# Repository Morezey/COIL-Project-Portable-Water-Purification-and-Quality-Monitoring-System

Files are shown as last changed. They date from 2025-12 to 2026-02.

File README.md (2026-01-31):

# Solar-Powered Water Purification & Quality Monitoring System

**Project Status:** Active | **Current Release:** Version 4 (Final Design)

## 📖 Project Overview
This project implements an automated water purification system with real-time quality monitoring. It features two distinct hardware configurations:
1.  **Scaled System (Part A):** High-capacity community unit (Seaflo Pump, 4-Stage Filtration + UV, solar powered).
2.  **Miniaturized System (Part B):** Portable tactical unit (R385 Pump, UF Membrane, Battery Powered).

---

## 📂 Repository Structure

```text
├── docs/                      # System design documentation
│   ├── version 1/             
│   ├── version 2/             
│   ├── version 3/             
│   └── version 4/            
│       ├── logical flow charts/
│       ├── system architecture/
│       └── system design review-v4.pdf
│
├── firmware/                  # ESP32 Source Code
│
├── hardware/                  # Hardware Design Files
│   ├── BOM/                   # Bill of Materials
│   ├── datasheets/            # Component Specifications
│   ├── PCB design/            # KiCad Project Files
│   └── simulations/           # Proteus Circuit Simulations
│
├── LICENSE
```

## 🚀 Getting Started
*   **Docs:** Start with `docs/version 4/system architecture` to understand the final system layout.
*   **Hardware:** Check the `hardware/simulations` folder to view the verified power and actuator circuits.
```

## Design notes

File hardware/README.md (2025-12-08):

The different files associated with the hardware components are placed here i.e.
- Schematics
- PCB layouts
- 3D models

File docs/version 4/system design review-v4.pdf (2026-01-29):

# Design and Implementation of a portable

# Water Purification and Quality Monitoring

# system

## Contents

PART A: SCALED SYSTEM | 3
1 Project Overview | 3
2 System Architecture and Hardware Layout | 3
3 System Operational Modes | 4
4 User Interface and Water Quality Standards | 9
5 Electrical Design and Simulation | 9
6 Bill of Materials Summary | 12
PART B: MINIATURIZED TACTICAL SYSTEM | 14
7 Project Overview | 14

8 System Architecture | 14
9 System Operational Modes | 15
10 Bill of Materials Summary (Miniaturized) | 20

## PART A: SCALED SYSTEM

## 1 Project Overview

Objective: To design an automated water purification and quality monitoring system prioritizing robust filtration performance, sensor accuracy, and operational safety.
The key features of the system include:
- Multi-stage filtration (Sediment, Carbon, and post filtration).
- UV treatment for disinfection.
- Real-time IoT quality monitoring.
- Automated self-protection mechanisms.

## 2 System Architecture and Hardware Layout

The system is made up of four different filters that operate in the pre-filtration phase, a UV lamp to kill microbial contaminants, and various sensors at different stages used to monitor the system and support the automation of the different actuators.

### 2.1 Hardware Block Diagram

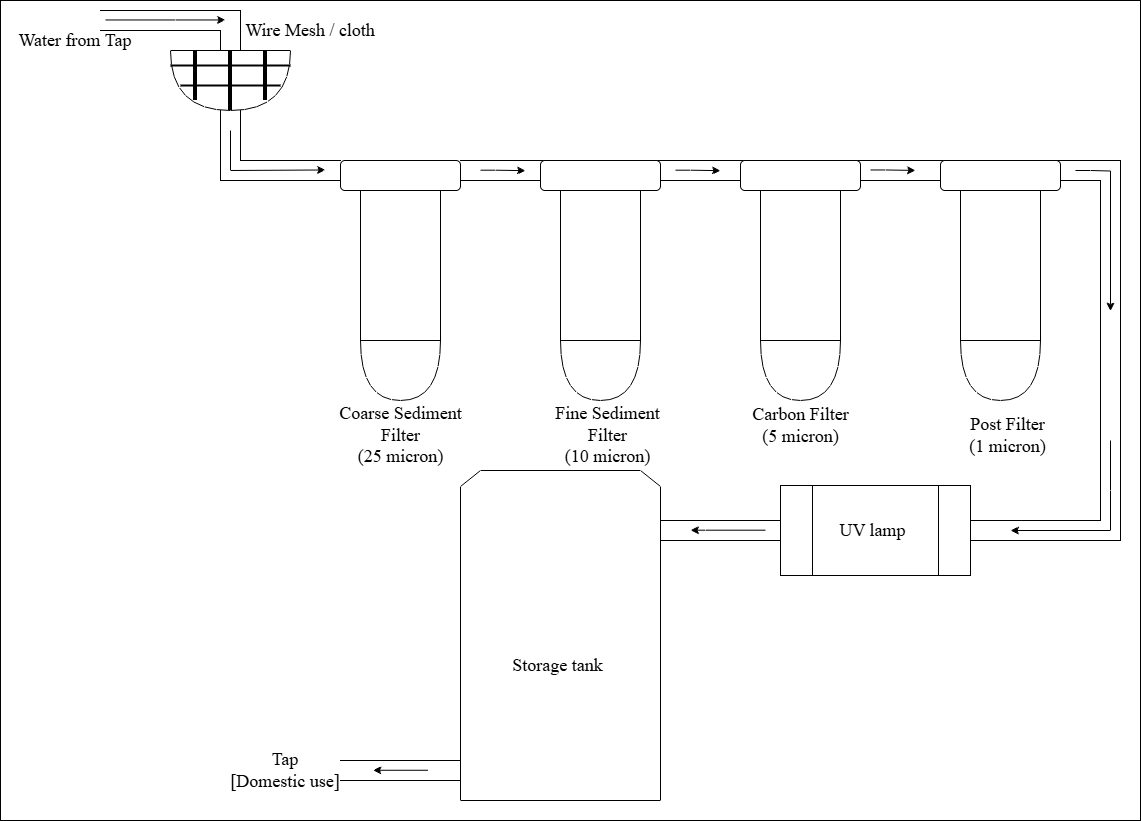
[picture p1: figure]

Figure 1: Hardware block diagram of the system.

### 2.2 Overall system representation

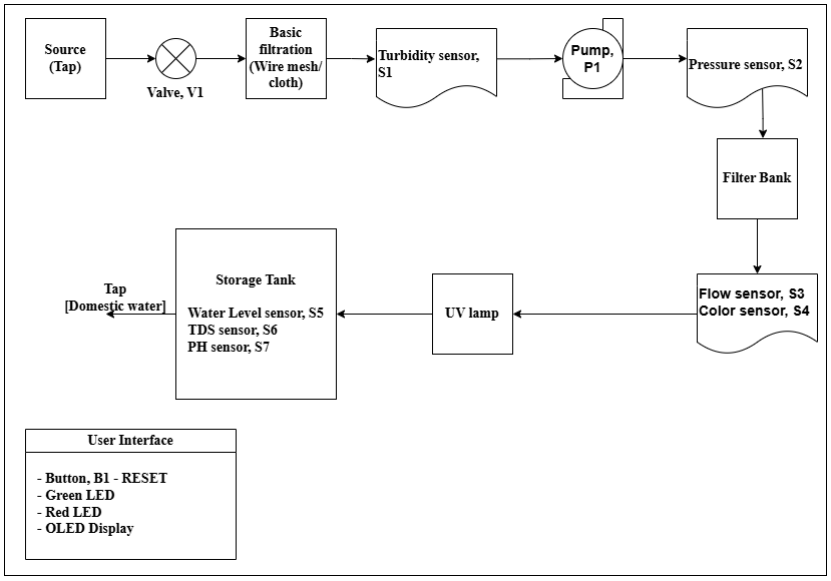
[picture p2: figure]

Figure 2: Overall system schematic representation.

During this stage, raw water is treated before storage. The process includes:
- Filtration: Water is drawn by pump P1 and passed through a filter bank consisting of two sediment filters (25 µm and 10 µm), an activated carbon 5 µm filter, and a 1 µm post-filter.
- System Protection: A pressure sensor (S2) and flow sensor (S3) monitor the

system conditions to detect clogs.
- Disinfection: A UV lamp is installed after the filter bank to reduce microbial load

before water enters the storage tank.

## 3 System Operational Modes

The system is designed with a microcontroller to monitor parameters and automate operations.

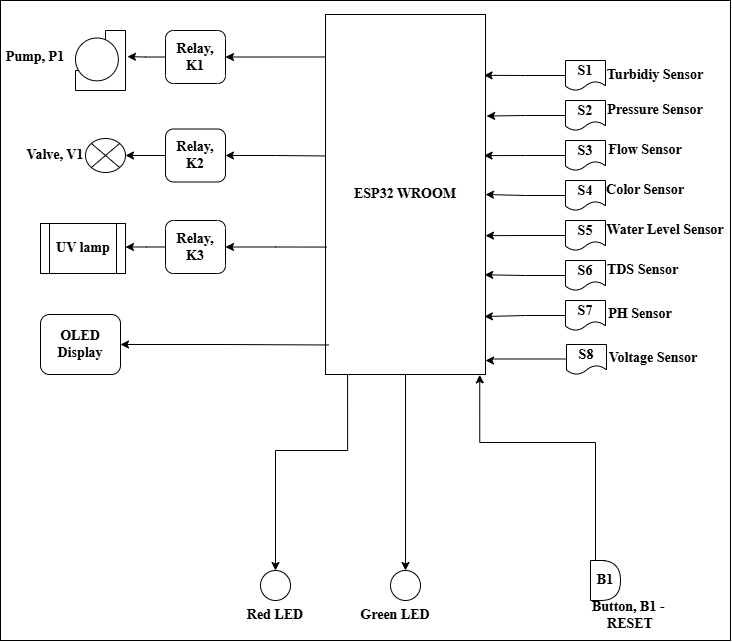
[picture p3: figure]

Figure 3: Microcontroller and component integration.

The microcontroller operates in three distinct modes to ensure safety, fault isolation, and energy efficiency:

### 3.1 Filtration Mode

Objective: To automatically fill the storage tank while protecting hardware components.

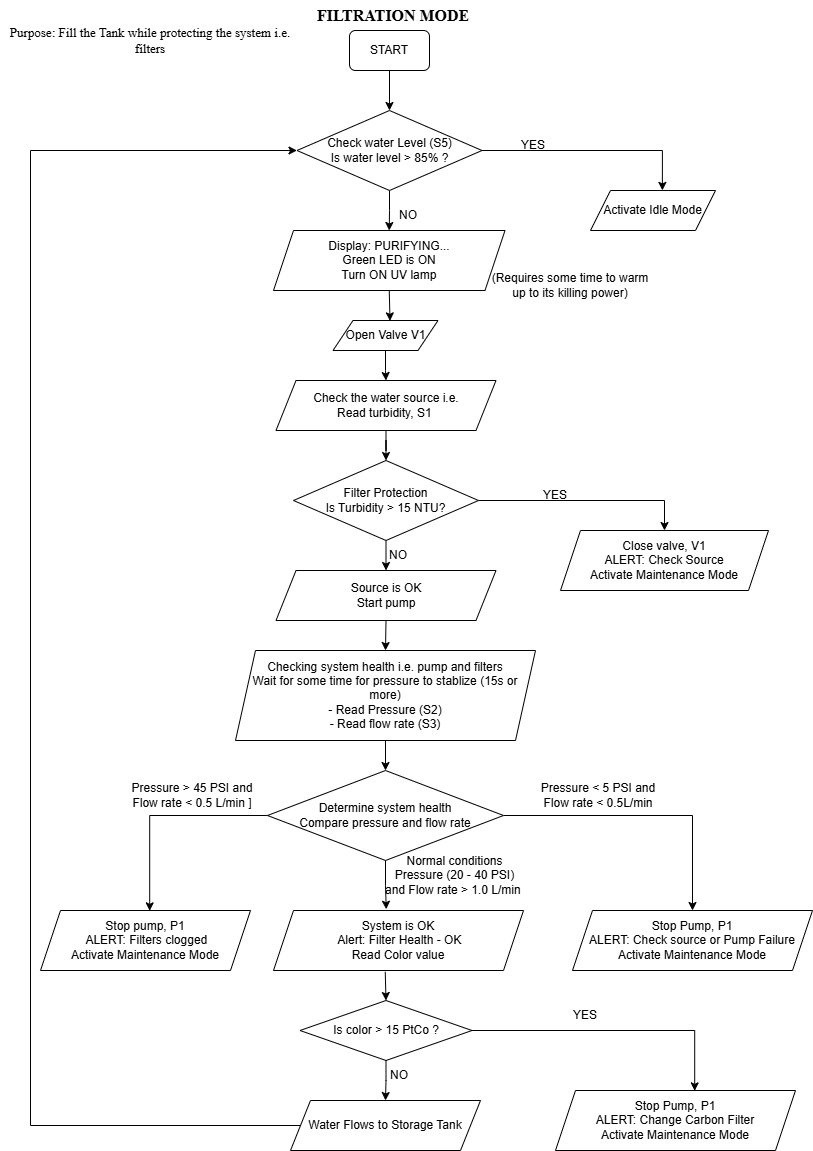
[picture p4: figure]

Figure 4: Filtration mode.

- UV Warm-up: The UV lamp activates before the pump starts to ensure no untreated water enters the storage tank.
- Clog and Dry Run Detection: The system differentiates faults by comparing

Pressure (S2) and Flow Rate (S3).
- Source Quality: Turbidity (S1) is checked to prevent fouling the filters. Color

(S4) is monitored to ensure effective UV transmission.

### 3.2 Idle Mode

Objective: To ensure energy conservation while monitoring the system.

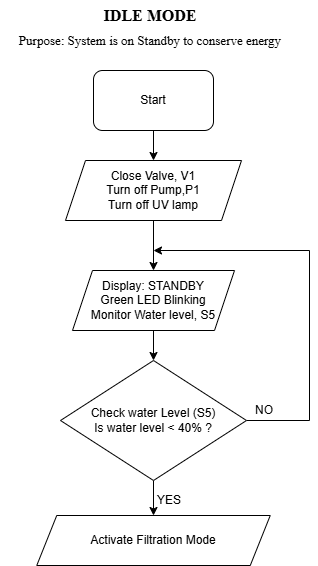
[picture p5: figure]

Figure 5: Idle mode.

- Activated when the storage tank is full (water level > threshold).
- High-power consumption components (Pump P1, UV Lamp) are turned OFF.
- Continuous Monitoring: The system wakes periodically to check the tank water

level.

### 3.3 Maintenance Mode

Objective: To lock the system during critical faults.

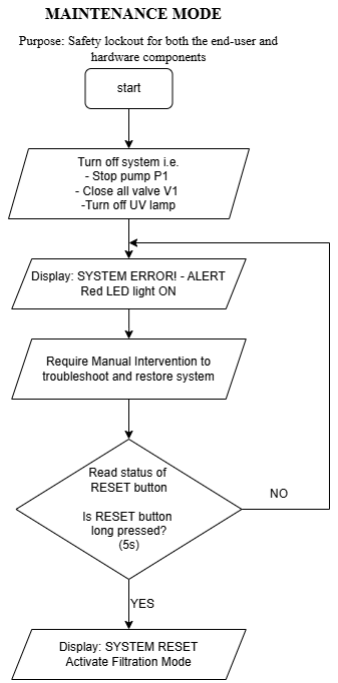
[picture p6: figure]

Figure 6: Maintenance mode.

- Activated by critical errors such as clogged filters or unsafe water parameters.
- System enters a full shutdown state, requiring manual intervention/reset from an

operator.

## 4 User Interface and Water Quality Standards

### 4.1 Status Indicators

The system communicates its operational state using an LED light interface and an OLED screen.

Table 1: System Status Indicators

LED Color | Mode | Description
Green blinking Idle | System ready / Tank full
Green | Filtration | System active and purifying
Red | Maintenance Critical fault (Technician required)

## 5 Electrical Design and Simulation

The PCB design integrates power management, signal conditioning for sensors, and actuator control. Simulations were conducted to verify circuit stability and safety before fabrication.

### 5.1 Power Management Simulation

The system is powered by a 12V Battery. The design includes a step-down conversion from 12V to 5V and 5V to 3.3V. Additionally, a Switched 5V Rail using a PMOS high-side switch allows the MCU to cut power to external sensors to conserve battery i.e. the sensors are only activated when readings are to be taken.

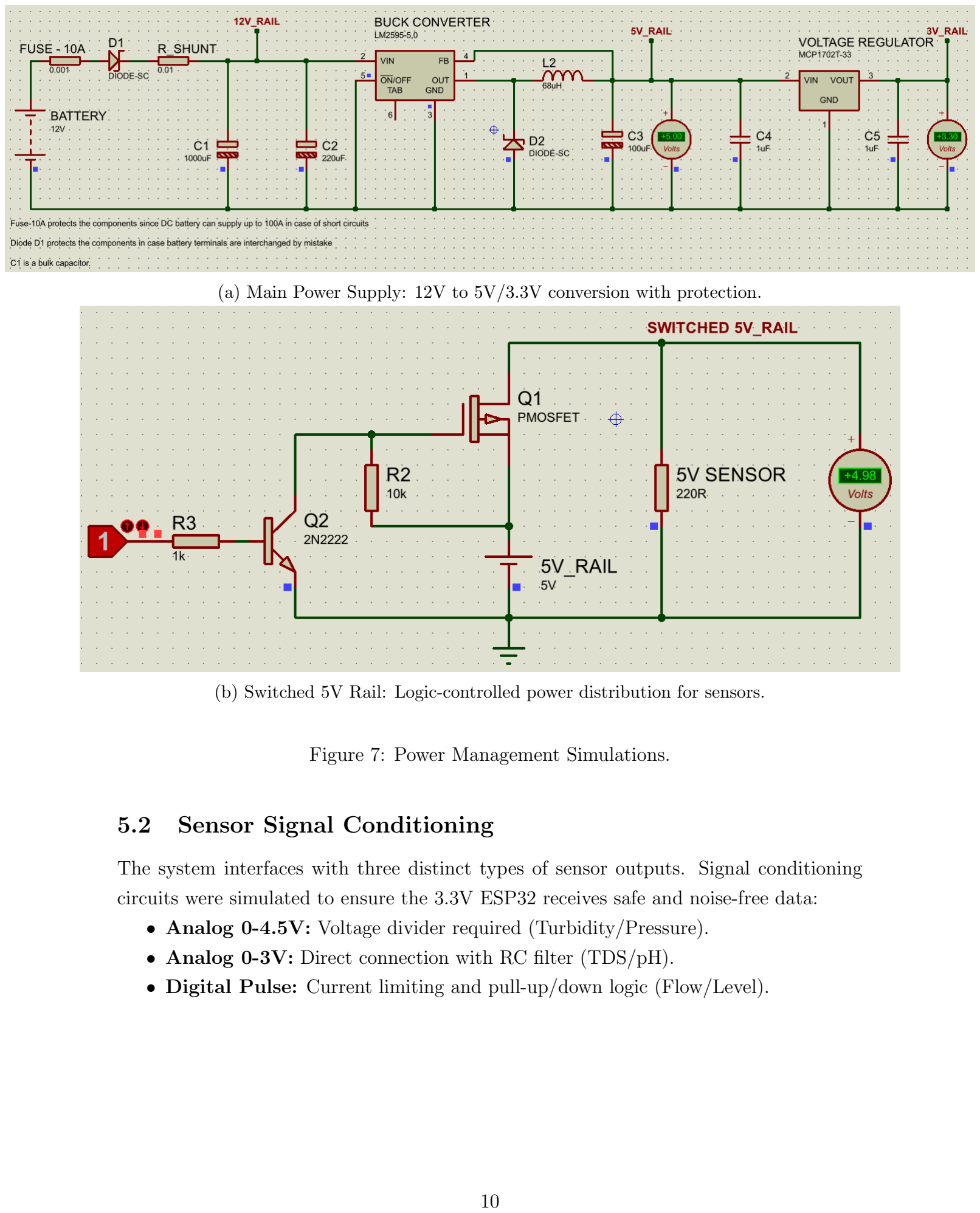
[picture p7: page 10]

(a) Main Power Supply: 12V to 5V/3.3V conversion with protection.
(b) Switched 5V Rail: Logic-controlled power distribution for sensors.

Figure 7: Power Management Simulations.

### 5.2 Sensor Signal Conditioning

The system interfaces with three distinct types of sensor outputs. Signal conditioning circuits were simulated to ensure the 3.3V ESP32 receives safe and noise-free data:
- Analog 0-4.5V: Voltage divider required (Turbidity/Pressure).
- Analog 0-3V: Direct connection with RC filter (TDS/pH).
- Digital Pulse: Current limiting and pull-up/down logic (Flow/Level).

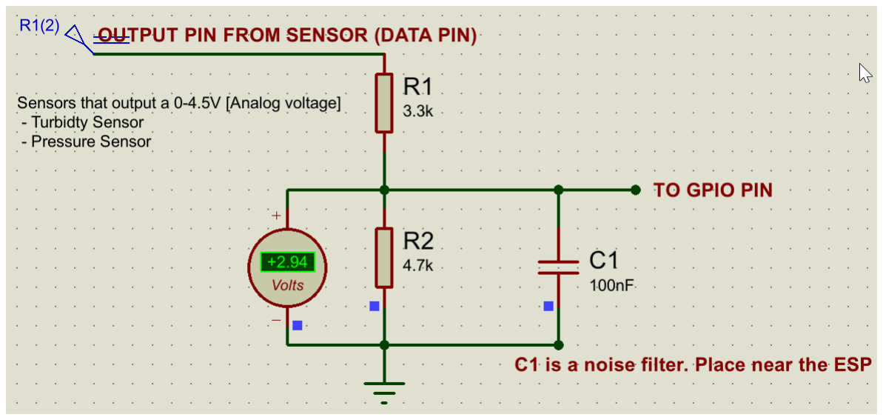
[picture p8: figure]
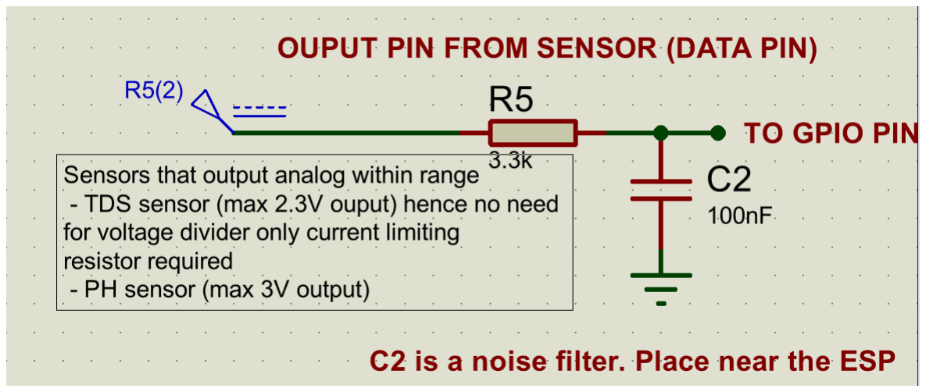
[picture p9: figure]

(a) 5V Analog Sensor (Voltage Divider). | (b) 3V Analog Sensor (Direct).

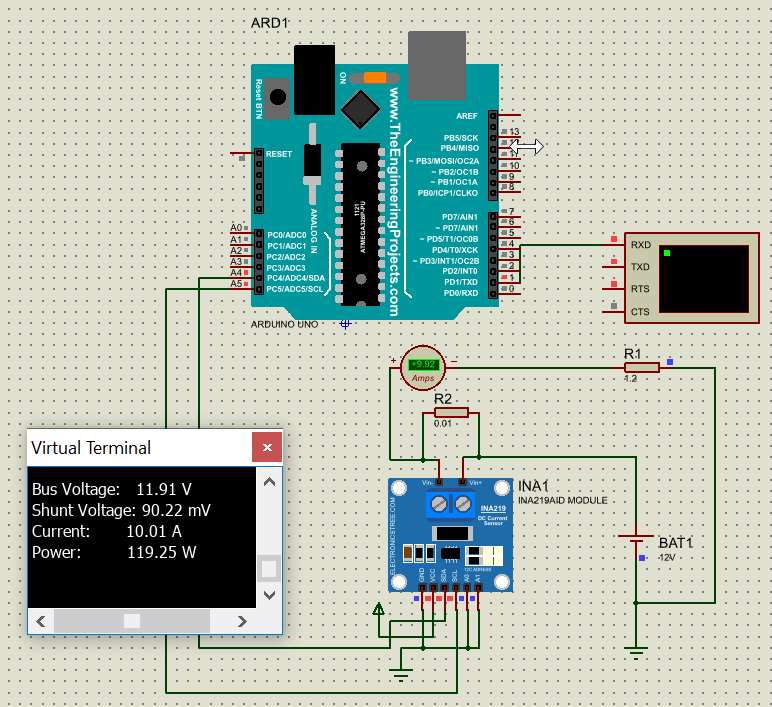
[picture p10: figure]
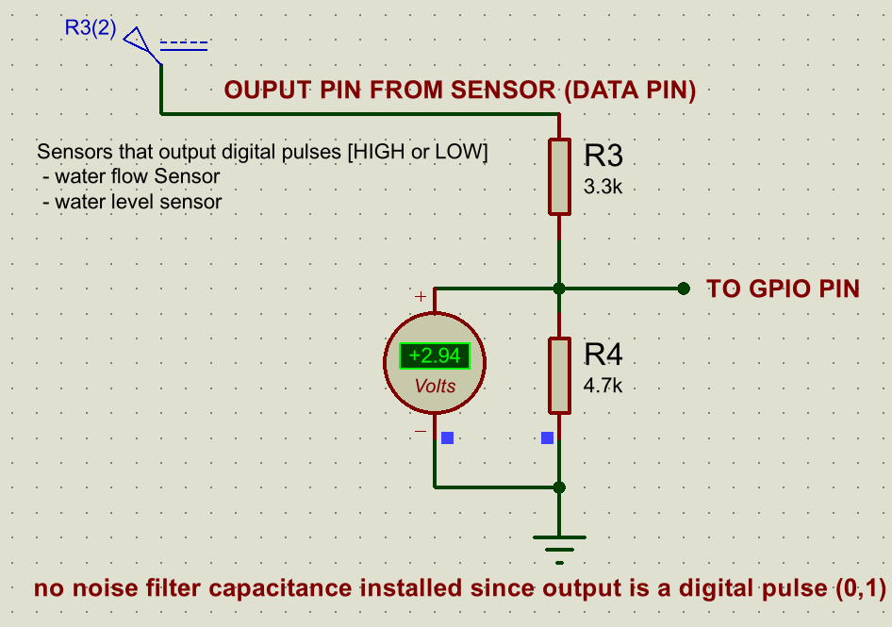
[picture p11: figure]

(c) Digital Sensor Interface. | (d) Extending the range of INA219.

Figure 8: Sensor signal conditioning and interface simulations.

### 5.3 Actuator Control Logic

High-current components (Pump, UV Lamp) are isolated from the MCU using Relays and NPN Transistors (2N2222). The simulation verifies that a logic signal from the MCU

successfully switches the 12V load.

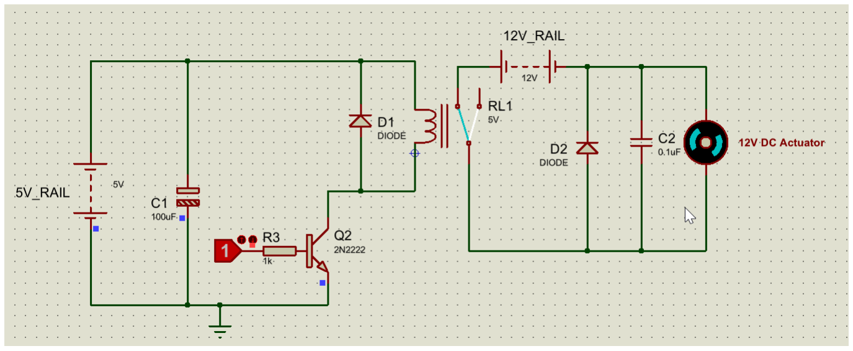
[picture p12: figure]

Figure 9: Actuator driver circuit with Relay and NPN transistor.

## 6 Bill of Materials Summary

### 6.1 External Hardware & Sensors

Table 2: Key External Components

Category | Component | Function
Filtration | 25µm, 10µm, 5µm (Carbon), 1µm | Multi-stage particulate & chemical removal
Sterilization 12W Stainless Steel UV Lamp (12V) Final disinfection
Actuators | Seaflo 12V Diaphragm Pump | Water delivery
| Solenoid Valve (12V) | Flow control
Sensors | Turbidity, TDS, pH, Color | Water Quality Monitoring
| Pressure, Flow, Level (Ultrasonic) | System Status Monitoring
Power | INA219 Voltage/Current Sensor | Real-time power consumption tracking

### 6.2 PCB Components

The custom PCB is built around the ESP32-S3 WROOM module. Total estimated cost for external hardware is approx. $370, and PCB components approx. $37.

Table 3: Key PCB Electronic Components

Subsystem | Component | Specification
MCU | ESP32-S3-WROOM-1 | Wi-Fi/BT enabled, Dual-core
Power | LM2595-5.0 | 3A Buck Converter (12V → 5V)
| MCP1702 | LDO Regulator (5V → 3.3V)
Switching | Songle Relay (SRD-05VDC) 5V Coil, switches 12V loads
| 2N2222A | NPN Transistor for relay driving
Connectors KF128 / KF350 | Screw terminals for external wiring

## PART B: MINIATURIZED SYSTEM

## 7 Project Overview

Objective: To design a portable, automated water filtration system capable of de-livering safe drinking water. The system prioritizes compactness, energy efficiency, and filter health.
The key features of the system include:
- Filtration system: This is made up of a hollow UF membrane and carbon filter.
- Power Saving mechanisms: Sleep mode capabilities for battery preservation.

## 8 System Architecture

### 8.1 Hardware Block Diagram

The system consists of a mesh intake, a micro-diaphragm pump (P1), a turbidity sensor (S1) for source monitoring, a pressure sensor (S2) for clog detection, and the composite

filter bank.

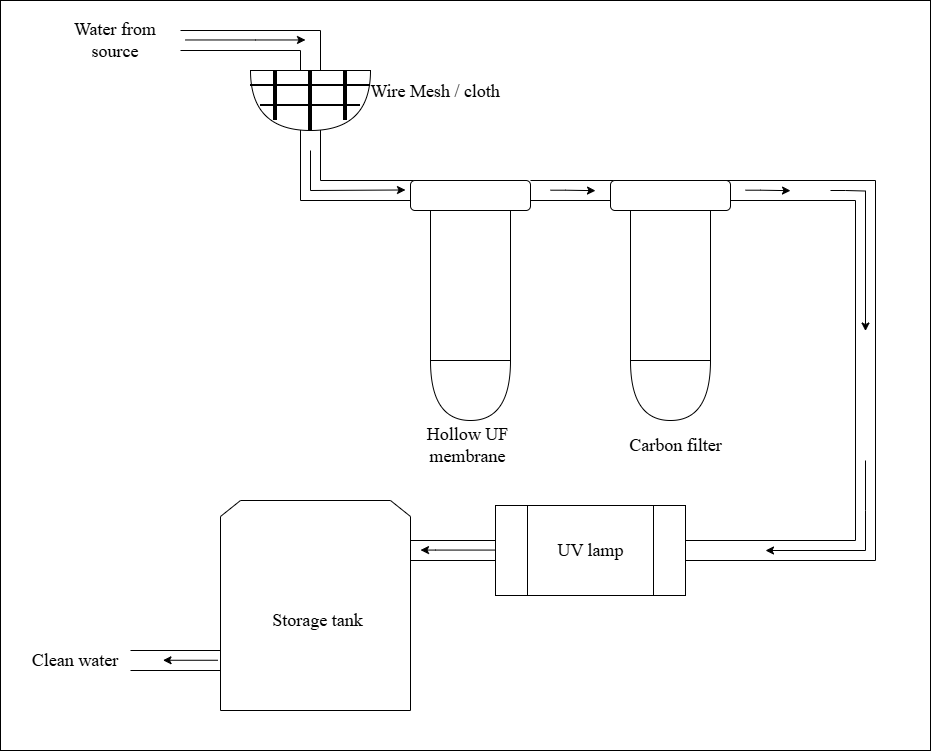
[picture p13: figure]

Figure 10: Hardware block diagram of the system.

### 8.2 Overall system representation

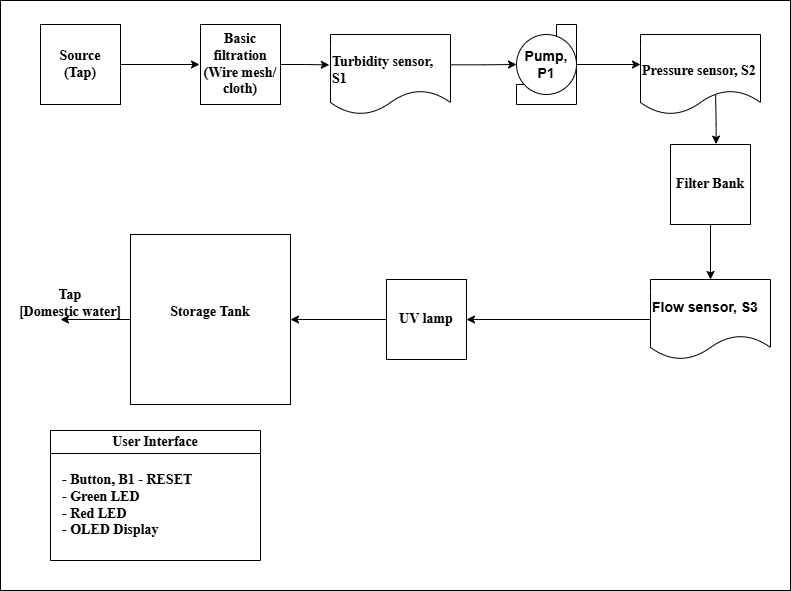
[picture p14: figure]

Figure 11: Overall system schematic representation.

### 8.3 Operational Process

- Pre-Filtration: Water is drawn by the Micro-Pump (P1). The intake hose has a

replaceable mesh (cloth) for basic filtration.
- Source Monitoring: A miniature Turbidity sensor (S1) analyzes the raw water. If

the water is too muddy (above a Threshold), the pump stops to prevent permanent

fouling of the filter.
- Primary Filtration: Water is forced through a Hollow Fiber Membrane. This removes bacteria and cysts physically (down to 0.1 µm) and reduces turbidity to

near-zero for the UV stage.
- System Protection: A miniature pressure sensor (S2) monitors back-pressure.

High pressure indicates the filter needs replacement.

## 9 System Operational Modes

The microcontroller manages the flow based on sensor feedback.

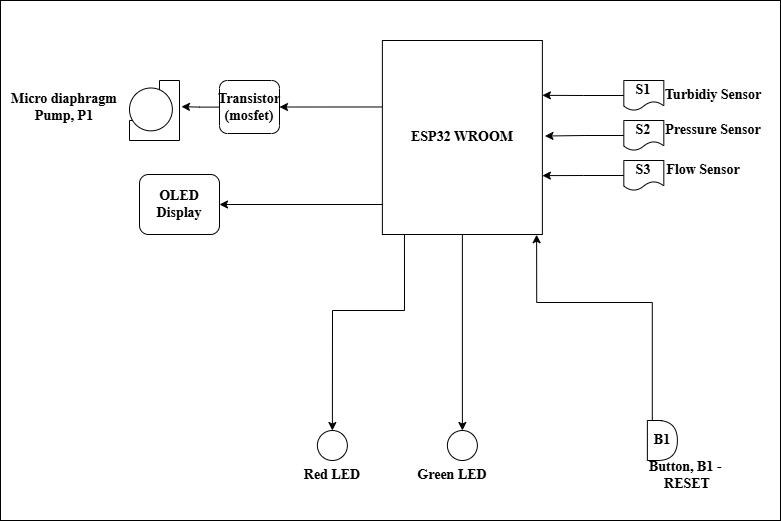
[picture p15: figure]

Figure 12: Microcontroller and component integration.

The microcontroller operates in three distinct modes to ensure safety, fault isolation, and energy efficiency:

### 9.1 Filtration Mode

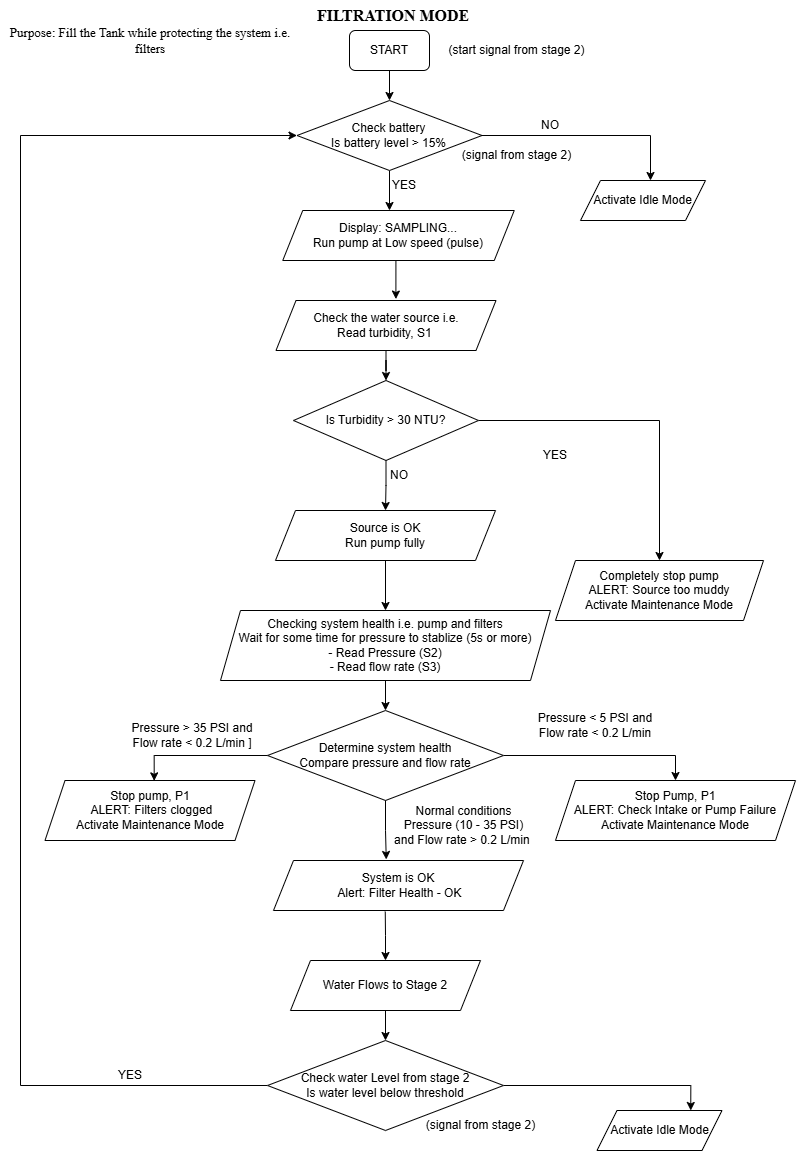
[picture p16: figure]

Figure 13: Filtration mode.

### 9.2 Idle Mode

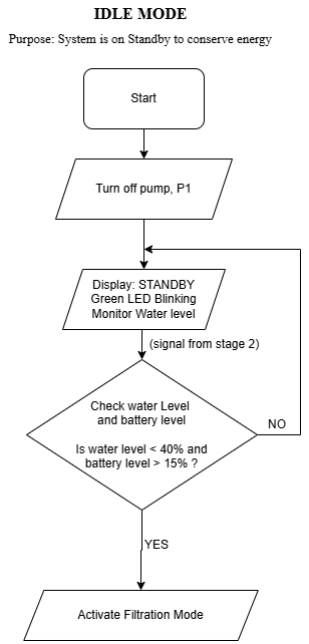
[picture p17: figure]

Figure 14: Idle mode.

### 9.3 Maintenance Mode

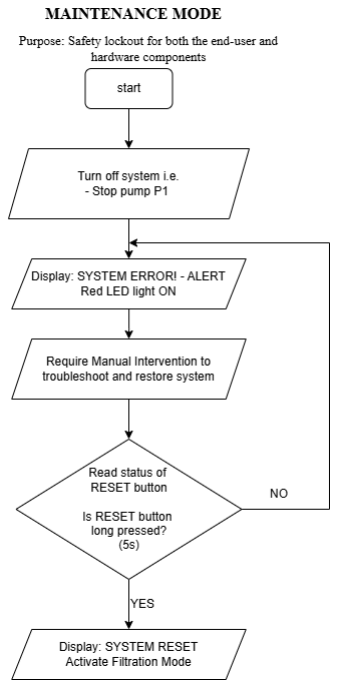
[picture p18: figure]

Figure 15: Maintenance mode.

## 10 Bill of Materials Summary (Miniaturized)

### 10.1 External Hardware & Sensors

Table 4: Key External Components (Miniaturized)

Category | Component | Function
Filtration | Hollow Fiber UF Membrane | Bacterial removal (0.1µm)
| Inline Sintered Carbon | Taste and odor removal
Actuators R385 Diaphragm Pump (6-12V) | Water delivery (Compact)
Sensors | TS-300B (Probe Only) | Turbidity Monitoring
Analog Pressure Transducer (80 PSI) Clog Detection
| YF-S401 Flow Sensor | Flow confirmation
Power | 2x 18650 Li-Ion Batteries | Portable Power Source

### 10.2 PCB Components

The miniaturized PCB focuses on compactness and power efficiency.

Table 5: Key PCB Electronic Components (Miniaturized)

Subsystem Component | Specification
MCU | ESP32-C3 SuperMini | Ultra-compact, Wi-Fi enabled
Power | TP5100 Module | Charging management for 2S Li-Ion
| LDO Regulator | 7.4V → 3.3V Logic power
Switching | IRLZ44N / AO3400 | N-Channel MOSFETs (Silent switching)
Interface | 12mm LED Ring Button Combined User Input/Status

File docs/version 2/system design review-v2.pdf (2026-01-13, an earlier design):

# Design and Implementation of a Water

# Purification and Quality Monitoring System

## 1 Project Overview

Objective: To design an automated water purification and quality monitoring system prioritizing robust filtration performance, sensor accuracy, and operational safety.
The key features of the system include:
- Multi-stage filtration (Sediment, Carbon, and post filtration).
- UV treatment for disinfection.
- Real-time IoT quality monitoring.
- Automated self-protection mechanisms.

## 2 System Architecture and Hardware Layout

The system is made up of four different filters that operate in the pre-filtration phase, a UV lamp to kill microbial contaminants, and various sensors at different stages used to monitor the system and support the automation of the different actuators.

### 2.1 Hardware Block Diagram


Figure 1: Hardware block diagram of the system.

### 2.2 Overall system representation

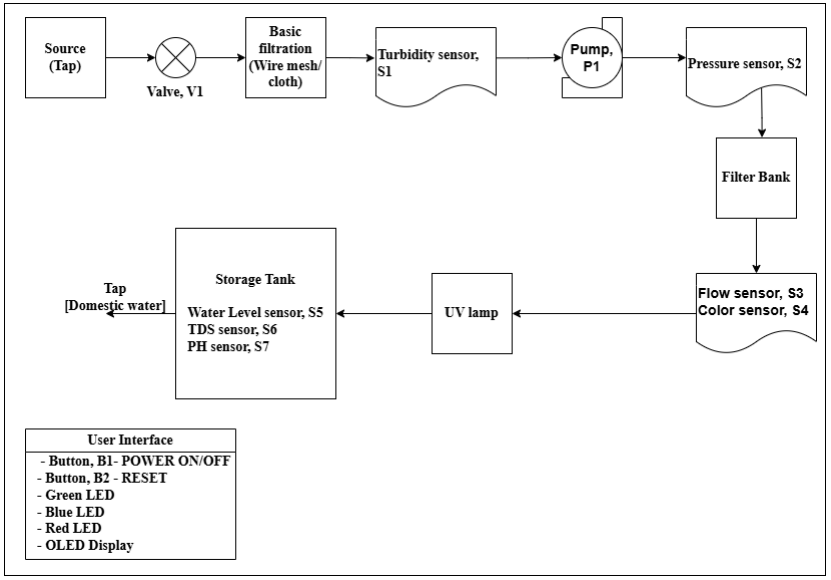
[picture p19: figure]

Figure 2: Overall system schematic representation.

During this stage, raw water is treated before storage. The process includes:
- Filtration: Water is drawn by pump P1 and passed through a filter bank consisting of two sediment filters (25 µm and 10 µm), an activated carbon 5 µm filter, and a 1 µm post-filter.
- System Protection: A pressure sensor (S2) and flow sensor (S3) monitor the

system conditions to detect clogs.
- Disinfection: A UV lamp is installed after the filter bank to reduce microbial load

before water enters the storage tank.

## 3 System Operational Modes

The system is designed with a microcontroller to monitor parameters and automate operations.

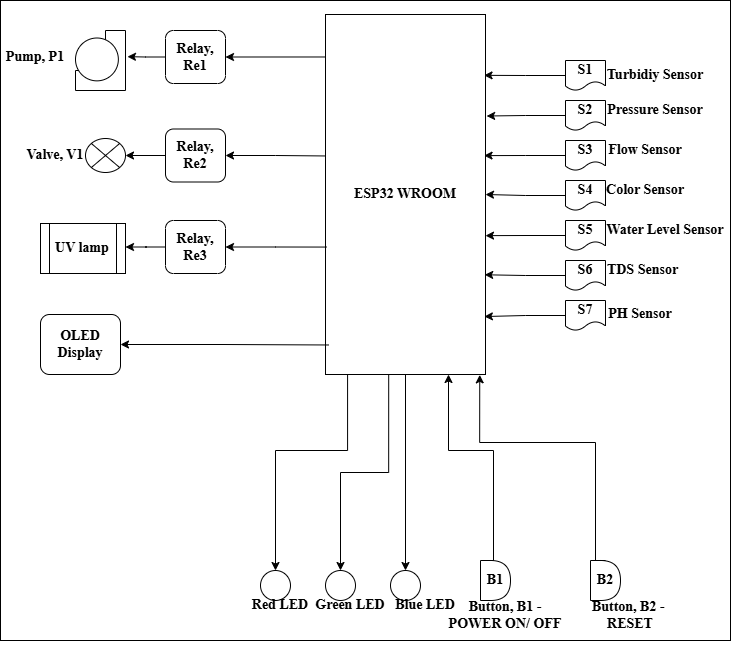
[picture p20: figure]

Figure 3: Microcontroller and component integration.

The microcontroller operates in three distinct modes to ensure safety, fault isolation, and energy efficiency:

### 3.1 Filtration Mode

Objective: To automatically fill the storage tank while protecting hardware components.


Figure 4: Filtration mode.

- UV Warm-up: The UV lamp activates before the pump starts to ensure no untreated water enters the storage tank.
- Clog and Dry Run Detection: The system differentiates faults by comparing

Pressure (S2) and Flow Rate (S3).
- Source Quality: Turbidity (S1) is checked to prevent fouling the filters. Color

(S4) is monitored to ensure effective UV transmission.

### 3.2 Idle Mode

Objective: To ensure energy conservation while monitoring the system.

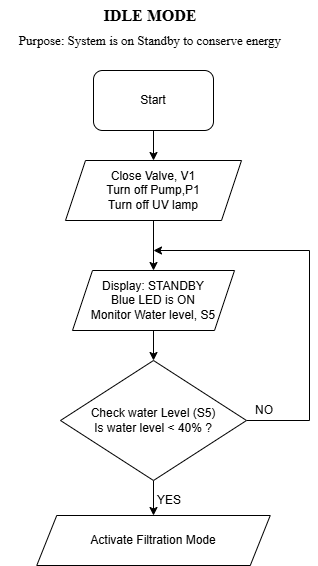
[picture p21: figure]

Figure 5: Idle mode.

- Activated when the storage tank is full (water level > threshold).
- High-power consumption components (Pump P1, UV Lamp) are turned OFF.
- Continuous Monitoring: The system wakes periodically to check the tank water

level.

### 3.3 Maintenance Mode

Objective: To lock the system during critical faults.

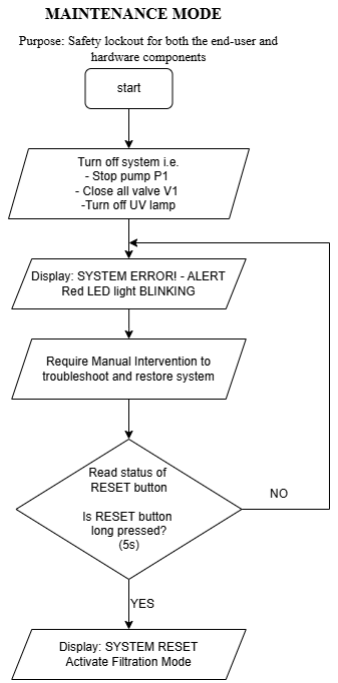
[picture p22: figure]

Figure 6: Maintenance mode.

- Activated by critical errors such as clogged filters or unsafe water parameters.
- System enters a full shutdown state, requiring manual intervention/reset from an

operator.

## 4 User Interface and Water Quality Standards

### 4.1 Status Indicators

The system communicates its operational state using an LED light interface and an OLED screen.

Table 1: System Status Indicators

LED Color | Mode | Description
Blue | Idle | System ready / Tank full
Green | Filtration / Dispensing System active and purifying
Red (Blinking) Maintenance | Critical fault (Technician required)

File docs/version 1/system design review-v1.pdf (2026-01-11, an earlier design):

# Design and Implementation of a Water

# Purification and Quality Monitoring System

## 1 Project Overview

Objective: To design an automated water purification and quality monitoring system prioritizing robust filtration performance, sensor accuracy, and operational safety.
The key features of the system include:
- Multi-stage filtration (Sediment, Carbon, and Ultra-filtration).
- UV treatment for disinfection.
- Real-time IoT quality monitoring.
- Automated self-protection mechanisms.

## 2 System Architecture and Hardware Layout

The system is divided into two main stages to improve efficiency and safety:
- Stage 1: Filtration and Storage.
- Stage 2: Polishing and Dispensing.

### 2.1 Hardware Block Diagram

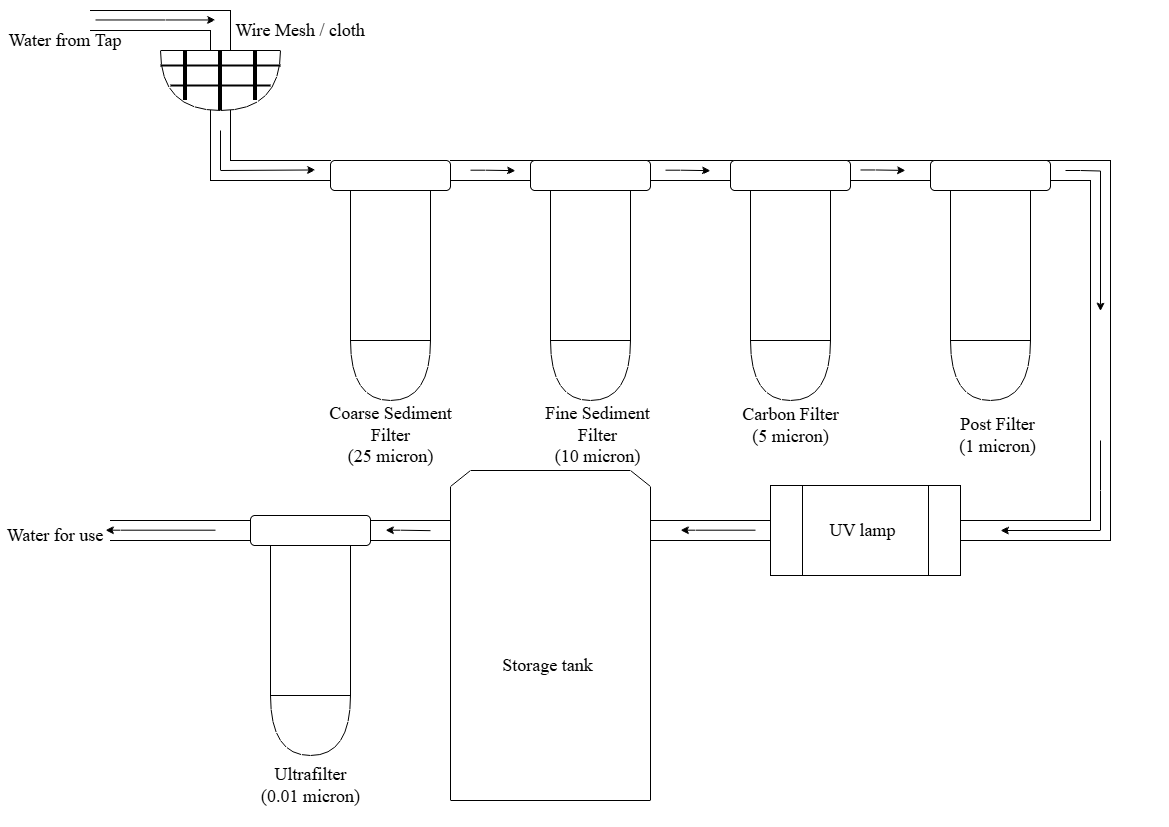
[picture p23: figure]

Figure 1: Hardware block diagram of the system.

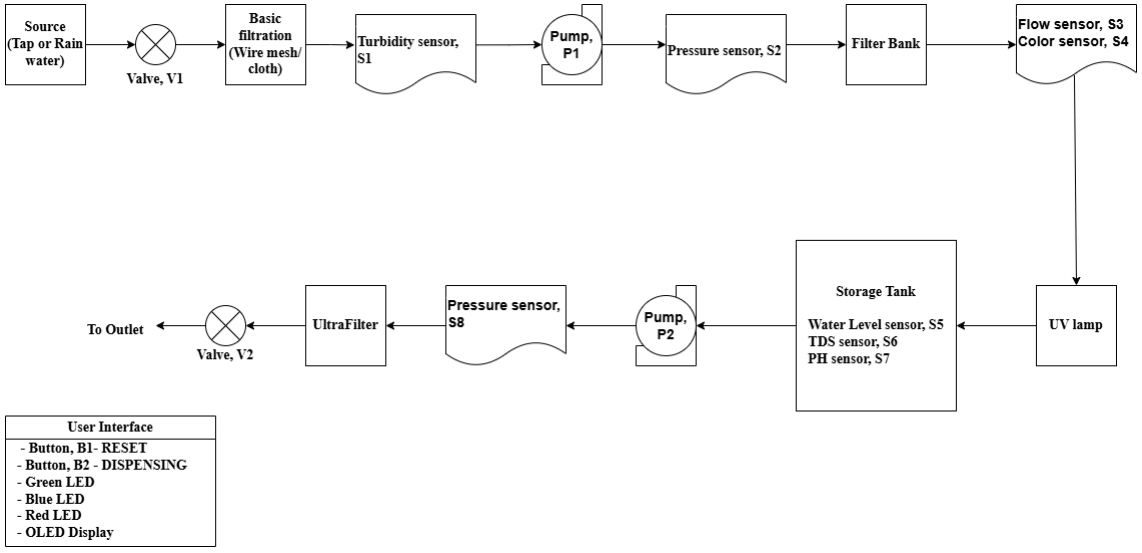
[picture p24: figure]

Figure 2: Overall system schematic representation.

### 2.2 Stage 1: Source to Storage Tank

During this stage, raw water is treated before storage. The process includes:
- Filtration: Water is drawn by pump P1 and passed through a filter bank consisting of two sediment filters (25 µm and 10 µm), an activated carbon 5 µm filter, and a 1 µm post-filter.
- System Protection: A pressure sensor (S2) and flow sensor (S3) monitor the

system conditions to detect clogs.
- Disinfection: A UV lamp is installed after the filter bank to reduce microbial load

before water enters the storage tank.

### 2.3 Stage 2: Storage Tank to End-User

The second stage ensures final polishing and safe delivery to the end-user.
- Polishing: Pump P2 drives water through a 0.01 µm ultrafilter membrane before

it is dispensed as a last line of defense.
- Safety Monitoring: Pressure sensor S8 monitors membrane pressure to detect

pressure buildups (clogs) or potential membrane ruptures.

## 3 System Operational Modes

The system is designed with a microcontroller to monitor parameters and automate operations.


Figure 3: Microcontroller and component integration.

The microcontroller operates in four distinct modes to ensure safety, fault isolation, and energy efficiency:

### 3.1 Filtration Mode

Objective: To automatically fill the storage tank while protecting hardware components.


Figure 4: Filtration mode.

- UV Warm-up: The UV lamp activates before the pump starts to ensure no untreated water enters the storage tank.
- Clog and Dry Run Detection: The system differentiates faults by comparing

Pressure (S2) and Flow Rate (S3).
- Source Quality: Turbidity (S1) is checked to prevent fouling the filters. Color

(S4) is monitored to ensure effective UV transmission.

### 3.2 Idle Mode

Objective: To ensure energy conservation while monitoring the system.


Figure 5: Idle mode.

- Activated when the storage tank is full (water level > threshold).
- High-power consumption components (Pump P1, UV Lamp) are turned OFF.
- Continuous Monitoring: The system wakes periodically to check the tank water

level.

### 3.3 Dispensing Mode

Objective: To ensure safe, on-demand delivery to the end-user.


Figure 6: Dispensing mode.

- Triggered by the user holding button B2.
- The system verifies that pH (S6) and TDS (S7) are within safe limits before opening

Valve V2.
- Active Ultrafilter health monitoring via pressure sensor S8.

### 3.4 Maintenance Mode

Objective: To lock the system during critical faults.


Figure 7: Maintenance mode.

- Activated by critical errors such as clogged filters or unsafe water parameters.
- System enters a full shutdown state, requiring manual intervention/reset from an

operator.

## 4 User Interface and Water Quality Standards

### 4.1 Status Indicators

The system communicates its operational state using an LED light interface and an OLED screen.

Table 1: System Status Indicators

LED Color | Mode | Description
Blue | Idle | System ready / Tank full
Green | Filtration / Dispensing System active and purifying
Red (Blinking) Maintenance | Critical fault (Technician required)

## 5 Recommendations

### 5.1 Removal of the ultrafiltration stage

This stage was intended as a substitute for the Reverse Osmosis membrane, which has low efficiency due to water loss; for every litre of purified water produced, approximately three litres are wasted. However, since the system considers tap water and rainwater at most, the ultrafiltration stage can be eliminated. This reduces cost and improves energy efficiency.

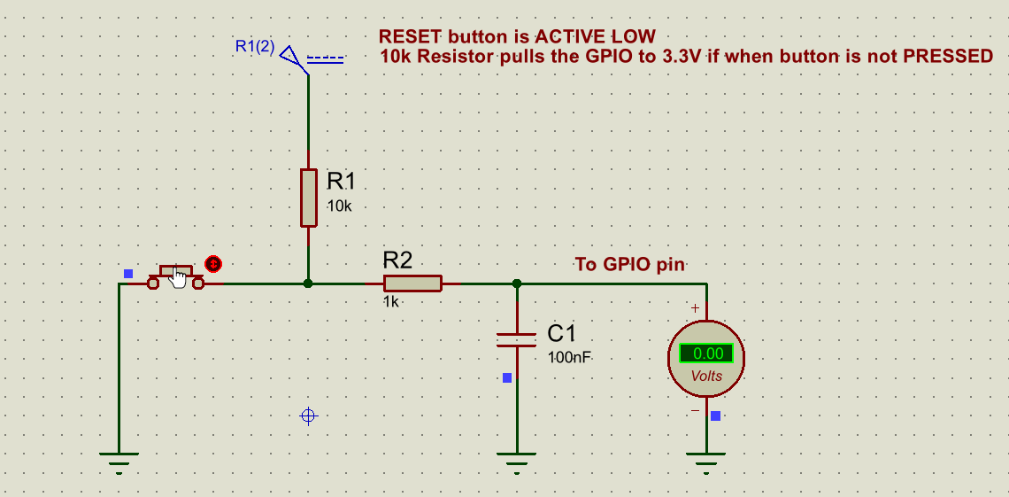
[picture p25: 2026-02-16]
hardware/simulations/images/WPS_RESET_button_sim.png

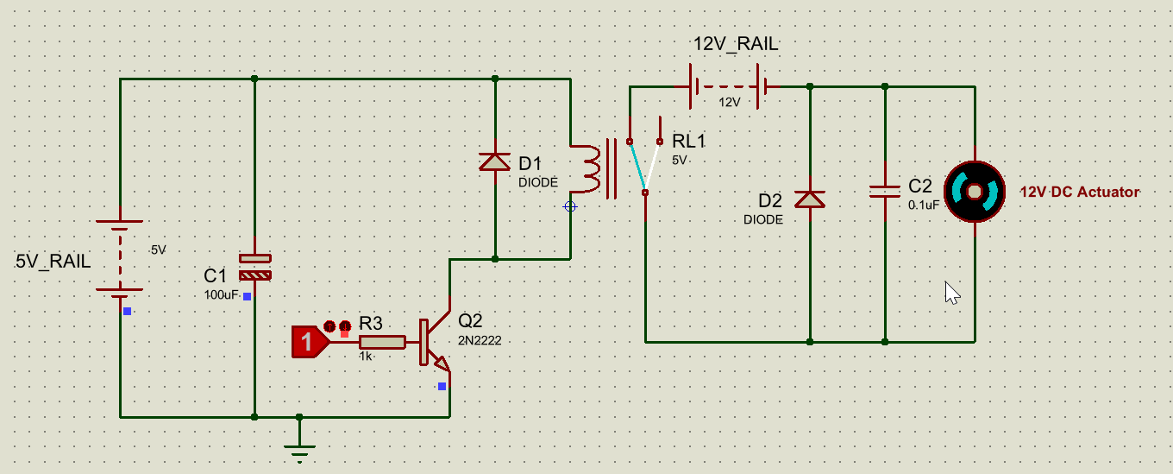
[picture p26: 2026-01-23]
hardware/simulations/images/WPS_Actuator_relay_sim.png

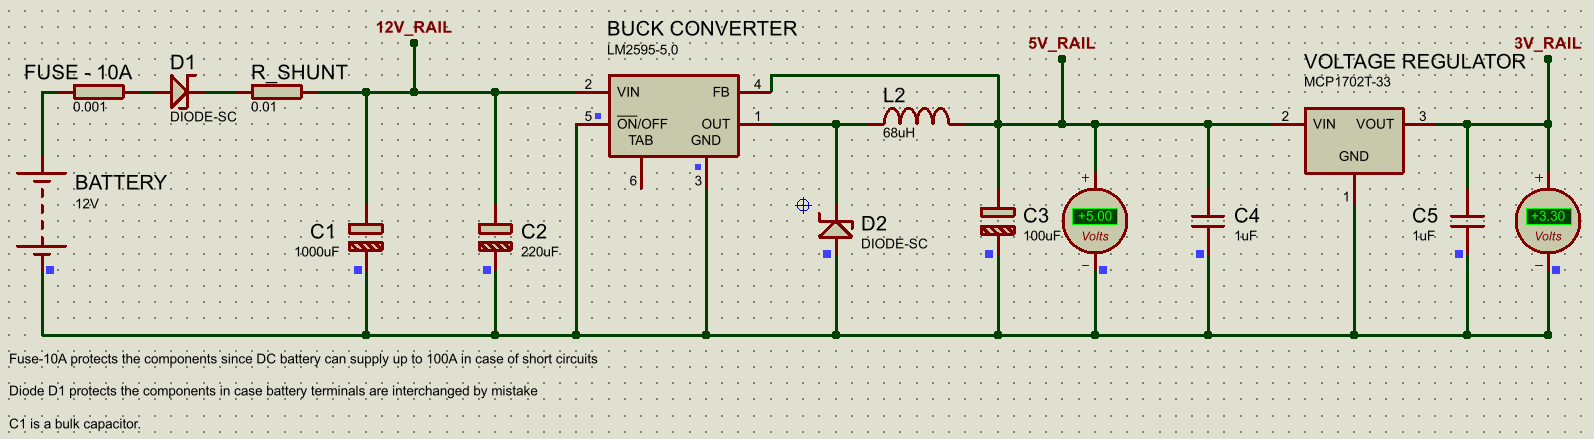
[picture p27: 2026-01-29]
hardware/simulations/images/WPS_Power_Supply_Sim.png

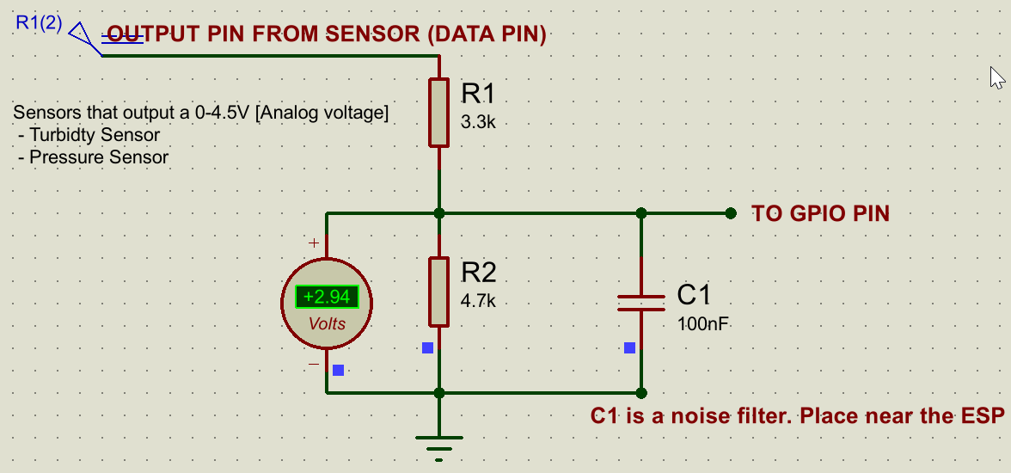
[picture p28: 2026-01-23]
hardware/simulations/images/WPS_sensors_voltage_output_sim (5V output sensors).png

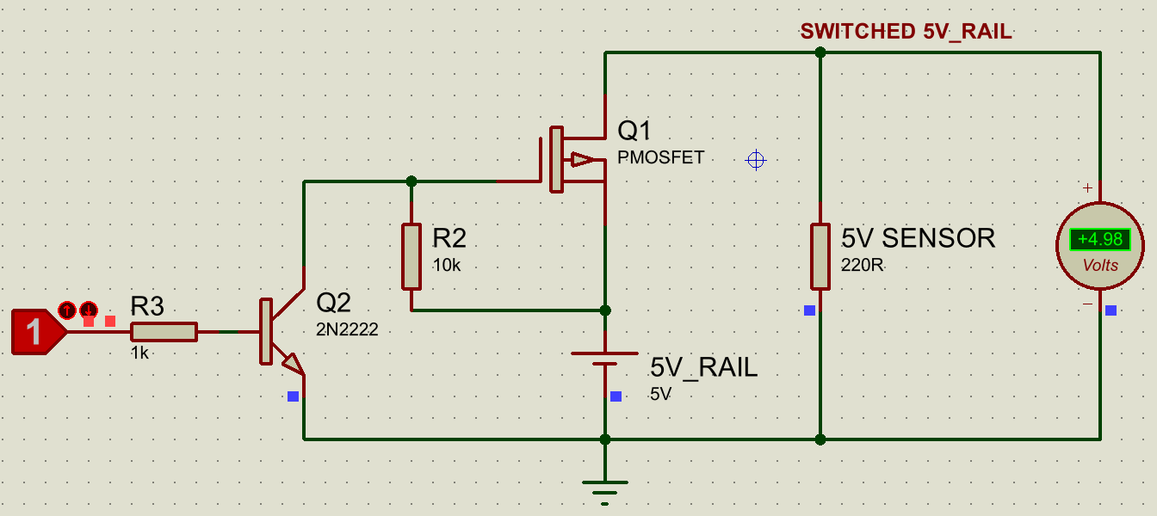
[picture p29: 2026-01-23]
hardware/simulations/images/WPS_Switched_5V_power_rail_sim.png

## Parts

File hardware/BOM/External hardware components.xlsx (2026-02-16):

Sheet: (Large) EXTERNAL COMPONENTS
Component | QTY | Description | Manufacturer | Manufacturer Part Number | Package / Footprint | Price (USD) | Find at (Supplier + URL) | Suppiler Part Number
25 micron sediment filter* | 1 | The Pentek WP Series string-wound cartridge is a durable, general-purpose sediment filter designed for municipal, well, and industrial water applications, using a precisely wound construction to provide higher surface area, improved filtration efficiency, and greater dirt-holding capacity while reducing sand, silt, scale, and rust; it has a 25-micron rating, measures 4.5" × 10", and fits standard 10" Big Blue housings. | Pentair Water | 355216-43 or WP5BB97P |  | 27.91 | Fresh water systems [https://www.freshwatersystems.com/collections/sediment-particulate-filters/products/pentek-wp25b97p-10-bb-string-wound-polypropylene-filter-25-micron]
10 micron sediment filter* | 1 | The Neo-Pure WPP-25098-10 is a cost-effective, surfactant-free polypropylene string-wound filter that meets USP Class VI and FDA CFR Title 21 requirements, offering high dirt-holding capacity and effective reduction of sand, silt, rust, dirt, and scale, while delivering reliable filtration for applications such as SDI, reverse osmosis, and CDI. | Neo-Pure | WPP-25098-10 or SW-25-1010 |  | 3.72 | Fresh water systems [https://www.freshwatersystems.com/collections/sediment-particulate-filters/products/neo-pure-wpp-25098-10-10-surfactant-free-string-wound-filter-10-micron]
5 micron carbon CTO filter* | 1 | KX MATRIKX CTO® filters are optimized for applications where they perform the role of both a sediment and activated carbon filter for chlorine taste and odor reduction. These filters are known industry-wide for superior performance. 5 Micron Nominal Filtration Rating (10 Micron Absolute Filtration Rating). | KX Technologies | 32-250-10-MATRIKX |  | 8.39 | WaterAnywhere [https://wateranywhere.com/products/10-standard-kx-matrikx-cto-carbon-block-filter-5-micron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]
1 micron post filter* | 1 | The Pentair DGD Series cartridge is a dual-gradient, 100% polypropylene sediment filter designed for Big Blue housings, offering high chemical resistance, protection against bacterial attack, and up to three times the dirt-holding capacity of standard sediment filters; with a 25-micron outer layer and 1-micron inner layer, it provides efficient pre- and post-filtration in a single cartridge for residential, municipal, and commercial applications, measures 10" × 4.5", and is NSF 42 and FDA CFR-21 certified. | Pentair Water | 155359-43 |  | 20.28 | Fresh Water Systems [https://www.freshwatersystems.com/products/pentair-10-bb-graded-density-polypropylene-sediment-filter-25-1-mic]
Filter housings* | 4 | The Pentek 10" Slim Line water filter housing features a reinforced polypropylene black cap and blue sump, providing high chemical compatibility, leak-proof sealing with a Buna-N O-ring, and reliable performance for low-flow applications such as sink filtration, pre- and post-reverse osmosis systems, and humidifying systems. | Pentair Water | 158005 |  | 76.04 | Fresh water systems [https://www.freshwatersystems.com/products/pentek-10-slim-line-water-filter-housing-black-blue-w-pr]
Water pipes*
Solar panel
battery |  | supply 12V
charge controller
connecting wires |  | Recommdended to use 16 AWG (1.31 mm²). Can draw 10 - 13 amps
switch (Power ON) | 1 | Rocker Switch SPST 16A(AC) 250V Through Hole | Legion | SS11-BBIWG-R20-R |  | 0.2 | LCSC [https://www.lcsc.com/product-detail/C309069.html] | C309069
button (RESET) | 1 | SPST-NO Through Hole 250V Pushbutton Switches RoHS | hanxia | HX PBS-33BXH+2.0 KJ-2PX100mm DT |  | 0.69 | LCSC [https://www.lcsc.com/product-detail/C5274681.html?s_z=n_Pushbutton%2520Switch%252012mm] | C5274681
LEDs | 2
OLED Display | 1 | Graphic LCD Display Module White OLED - Passive Matrix I2C, SPI 0.96" (24.38mm) 128 x 64 [ensure to use I2C] | Adafruit Industries LLC | 326 |  | 17.5 | DigiKey [https://www.digikey.com/en/maker/projects/arduino-oled-display-interfacing/0a150e86a90a4743b361376ba0d39722]
Solenoid Valve, V1 | 1 | This is the physical device installed on the water pipe | Adafruit Industries LLC |  |  | 6.95 | DigiKey [https://www.digikey.com/en/products/detail/adafruit-industries-llc/997/6827136 | 1528-2003-ND
12 V DC Diaphragm pump, P1 | 1 | This pump draws water from the source and pushes it through the Sediment/Carbon filters. | Seaflo | SFDP1-011-070-21 |  | 34 | Amazon [https://www.amazon.com/SEAFLO-Diaphragm-Water-Pressure-Pump/dp/B0DVTJ1FKP] | 810039497982
Turbidity sensor, S1 | 1 | GRAVITY: ANALOG TURBIDITY SENSOR | DFRobot | SEN0189 |  | 9.9 | DigiKey [https://www.digikey.com/en/products/detail/dfrobot/SEN0189/6588606?s=N4IgTCBcDaIMoFEByAGAjADgJwgLoF8g] | 1738-1185-ND
Pressure sensor, S2 | 1 | Pressure Sensor 232.06PSI (1600kPa) Gauge 0.5 V ~ 4.5 V Cylinder, Metal | DFRobot | SEN0257 |  | 17.5 | DigiKey [https://www.digikey.com/en/products/detail/dfrobot/SEN0257/8341836 | 1738-1377-ND
Water Flow sensor, S3 | 1 | Liquid Flow Sensor 1 ~ 30 LPM 0.787" (20mm) Plastic | DFRobot | SEN0217 |  | 8.99 | DigiKey [https://www.digikey.com/en/products/detail/dfrobot/SEN0217/6579446?s=N4IgTCBcDaIM4FMB2AGMBGA7CAugXyA] | SEN0217-ND
Color sensor, S4 | 1 | TCS34725 Color Sensor Gravity Platform Evaluation Expansion Board | DFRobot | SEN0212 |  | 7.9 | DigiKey [https://www.digikey.com/en/products/detail/dfrobot/SEN0212/7087188?s=N4IgTCBcDaIMoFEByAGMBGCBdAvkA] | 1738-1291-ND
Water Level sensor, S5 | 1 | WEATHER-PROOF ULTRASONIC SENSOR | DFRobot | SEN0208 |  | 16 | DigiKey [https://www.digikey.com/en/products/detail/dfrobot/SEN0208/6588472] | 1738-1050-ND
TDS sensor, S6 | 1 | GRAVITY ANALOG TDS SENSOR/METER | DFRobot | SEN0244 |  | 11.8 | DigiKey [https://www.digikey.com/en/products/detail/dfrobot/SEN0244/8019062?s=N4IgTCBcDaIMoFEByAGMAWdIC6BfIA] | 1738-1368-ND
PH sensor, S7 | 1 | GRAVITY: ANALOG PH SENSOR/METER | DFRobot | SEN0161-V2 |  | 39.5 | DigiKey [https://www.digikey.com/en/products/detail/dfrobot/SEN0161-V2/9608223?s=N4IgTCBcDaIMoFEByAGAjANjQWgGoQF0BfIA] | SEN0161-V2-ND
Voltage sensor, S8 | 1 | This breakout board will solve all your power-monitoring problems. Instead of struggling with two multimeters, you can just use the handy INA219 chip on this breakout to both measure both the high side voltage and DC current draw over I2C with ±1% precisio | Adafruit | 1NA219 |  | 9.95 | Adafruit [https://www.adafruit.com/product/904#technical-details]
*UV Lamp | 1 | 12 Watt Stainless Steel UV Sterilizer with 12V ballast [DC not AC] |  | * SSE-012 EB-G16-12V UV Sterilizer |  | 70 | https://purewater4life.co.za/12-watt-stainless-steel-uv-sterilizer-with-12v-ballast/
TOTAL |  |  |  |  |  | 387.22

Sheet: (MINI) EXTERNAL COMPONENTS
Component | QTY | Description | Manufacturer | Manufacturer Part Number | Package / Footprint | Price (USD) | Find at (Supplier + URL) | Suppiler Part Number
Hollow UF membrane | 1 | A lightweight, palm-sized Sawyer Mini water filtration kit that includes a reusable pouch, syringe, and straw, offering high-performance 0.1-micron filtration to remove bacteria, protozoa, and microplastics, with versatile compatibility for outdoor use, travel, and emergency preparedness. | Sawyer |  |  | 28.99 | sawyer.com [https://www.sawyer.com/product/mini-water-filtration-system-blue#product-details]
Carbon filter | 1 | A Ronaqua T33 inline coconut-shell activated carbon filter designed for reverse osmosis systems and similar applications, used as a pre/post polishing stage to improve water taste and odor, NSF-certified, easy to install, and typically replaced every two years. | Ronaqua | ‎FBA_RA-T33 |  | 12.49 | amazon.com [https://www.amazon.com/Inline-Coconut-Activated-Membrane-Reduction/dp/B0719SHH9X?th=1]
Turbidity sensor
Micro Pressure sensor |  | Search: "Pressure Transducer Sensor 5V 80psi".
Flow sensor |  | buy the small one |  | YF-S401
Micro Diaphragm pump
Mechanical check valve

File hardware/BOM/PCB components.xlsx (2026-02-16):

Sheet: PWR MGT
Component | Label | Value | Description | Manufacturer | Manufacturer Part Number | Symbol | Footprint | 3dModel | Price (USD) | Supplier | Supplier Part Number | Notes
input connector | J1 |  | 2 Position Wire to Board Terminal Block Through Hole 5.08mm | Cixi Kefa Elec | KF128-5.08-2P-AA | KF128-5.08-2P | CONN-TH_P5.08_KF128-5.08-2P | CONN-TH_P5.08_KF128-5.08-2P | 0.91 | LCSC [https://www.lcsc.com/product-detail/C474952.html?s_z=n_C474952] | C474952 | Input 12V from the battery consider a two pin connector Screw Terminal Block (2-pin, 5.08mm pitch)
fuse* | F1 | 16V 9A | Polymeric PTC Resettable Fuse 16V 9A Through Hole P=5.1mm | JDTfuse | A16-900 | A16-900 | FUSE-TH_L15.0-W3.0-P5.08-D1.0-S1.2 | FUSE-TH_L15.0-W3.0-P5.08-D1.0-S1.2 | 0.4 | LCSC [https://www.lcsc.com/product-detail/C135397.html] | C135397 | *Fuse-10A protects the components (determined from maximum current drawn from the circuit - calculation needed) since DC battery can supply up to 100A in case of short circuits. Prefferealbe a resettable PTC fuse
electrolytic capacitor | C1 | 1000 uF | 1000uF 25V Aluminum Electrolytic Capacitors Through Hole 10000hrs@125℃ | KNSCHA | 01EC4294SHC1000UF25V | C_Polarized | CAP-TH_BD10.0-P5.00-D1.0-FD | CAP-TH_D10.0-H16.0-P5.00 | 0.1 | LCSC [https://www.lcsc.com/product-detail/C503217.html] | C503217 | C1 is a bulk capacitor. Consider an electrolyte capacitor for this scenario
schottky diode | D1 |  | Diode Independent 40V 5A Through Hole DO-27 | LGE | SR540 | SR540_C432150 | DO-27_BD5.2-L8.9-P12.90-D1.5-RD |  | 0.1 | LCSC [https://www.lcsc.com/product-detail/C432150.html?s_z=n_SR540] | C432150 | Diode D1 protects the components in case battery terminals are interchanged by mistake
buck converter* | U1 |  | 150kHz Buck Fixed 5V 3A TO-220-5 Voltage Regulators - DC DC Switching Regulators RoHS | HGSEMI | LM2595T-5.0 | LM2595T-5.0 | TO-220-5L_L10.2-W4.5-P1.71-L | C316671 | 0.67 | LCSC [https://www.lcsc.com/product-detail/C316671.html?s_z=n_LM2595] | C316671 | convert 12V to 5V to power 5V components. Package type TO-263 i.e. LM2596HVT -5.0 or LM2596T -5.0 [the one used in simulation has a rating of 1A. Change this to 3A when sourcing]
electrolytic capacitor* | C2 | 470uF / 25V | 220uF 25V Aluminum Electrolytic Capacitors Through Hole 2000hrs@105℃ | Rubycon | 25YXJ470M10X12.5 | C_Polarized | CAP-TH_BD10.0-P5.00-D1.0-FD | CAP-TH_D10.0-H16.0-P5.00 | 0.2 | LCSC [https://www.lcsc.com/product-detail/C88740.html] | C88740
schottky diode | D2 |  | Diode Independent 40V 5A Through Hole DO-27 | LGE | SR540 | SR540_C432150 | DO-27_BD5.2-L8.9-P12.90-D1.5-RD |  | 0.1 | LCSC [https://www.lcsc.com/product-detail/C432150.html?s_z=n_SR540] | C432150
Inductor* | L1 | 33 uH | 3A 68uH 3A Toroidal inductor ±5% Through Hole,6.7x14.9mm Fixed Inductors RoHS | XR | XR050125T680M-V | L | IND-TH_L14.0-W6.5-P8.00-D0.6 | IND-TH_L14.0-W6.5-H14.0-P8.00-D0.6 | 0.88 | LCSC [https://www.lcsc.com/product-detail/C7462889.html?s_z=n_Toroid%2520Inductor%252068uH] | C7462889
electrolytic capacitor* | C3 | 330uF / 10V or 16V | 100uF 10V Aluminum Electrolytic Capacitors Through Hole,D5xL11mm 4000hrs@105℃ | Econd | 330uF10V6.3x11GF | C_Polarized | CAP-TH_BD6.3-P2.50-D0.6-FD | CAP-TH_BD6.3-P2.50-D0.6-FD | 0.1 | LCSC[https://www.lcsc.com/product-detail/C49304925.html] | C49304925
schottky diode | D11 |  | Diode Independent 40V 5A Through Hole DO-27 | LGE | SR540 | SR540_C432150 | DO-27_BD5.2-L8.9-P12.90-D1.5-RD |  | 0.1 | LCSC [https://www.lcsc.com/product-detail/C432150.html?s_z=n_SR540] | C432150 | prevent current from usb into the input of the converter
3.3. Volatage Regulator* | U2 |  | 3.3V 5.5V Positive Fixed SOT-223 Voltage Regulators - Linear, Low Drop Out (LDO) Regulators RoHS | TI | TLV1117LV33DCYR | TLV1117LV33DCYR | SOT-223_L6.7-W3.5-P2.30-BR | SOT-223-4P_L6.5-W3.5-H1.6-LS7.0-P2.30 | 0.2 | LCSC [https://www.lcsc.com/product-detail/C15578.html] | C15578 | convert 5V to 3.3V for the microcontroller. Package type AMS1117 SOT-89-3L - 3.3 S:SOT-89-3L [simulation, used the MCP1702T-33] change to something with output current of 1A
ceramic capacitor | C4 | 1 uF | 1uF ±10% 50V Ceramic Capacitor X7R Through Hole,P=5.08mm | KNSCHA | 178MU0014 | C | CAP-TH_L4.4-W4.0-P5.08-D0.6 | CAP-TH_L4.4-W4.0-P5.08-D0.6 | 0.1 | LCSC [https://www.lcsc.com/product-detail/C5632438.html] | C5632438
ceramic capacitor | C5 | 1 uF | 1uF ±10% 50V Ceramic Capacitor X7R Through Hole,P=5.08mm | KNSCHA | 178MU0014 | C | CAP-TH_L4.4-W4.0-P5.08-D0.6 | CAP-TH_L4.4-W4.0-P5.08-D0.6 | 0.1 | LCSC [https://www.lcsc.com/product-detail/C5632438.html] | C5632438
resistor | R1 | 1k | 1kΩ 250mW Metal Film Resistor ±100ppm/℃ ±1% Through Hole,D2.4xL6.3mm Through Hole Resistors RoHS | YAGEO | MFR-25FRF52-5K1 | R | RES-TH_BD2.4-L6.3-P10.30-D0.6 | RES-TH_BD2.4-L6.3-P10.30-D0.6 | 0.1 | LCSC [https://www.lcsc.com/product-detail/C1744271.html?s_z=n_resistor] | C1744271
transistor | Q1 |  | Bipolar (BJT) Transistor NPN 40V 600mA 250MHz 625mW Through Hole TO-92 | ST(Semtech) | 2N2222A | 2N2222 | TO-92-3_L4.9-W3.7-P1.27-L | TO-92-3_L4.9-W3.7-P1.27-L | 0.04 | LCSC [https://www.lcsc.com/product-detail/C118536.html?s_z=n_2N2222] | C118536 | required a npn (2N222)
resistor | R2 | 10k | 10kΩ 250mW Metal Film Resistor ±100ppm/℃ ±1% Through Hole,D2.4xL6.3mm Through Hole Resistors RoHS | YAGEO | MFR-25FRF52-5K1 | R | R_Axial_DIN0207_L6.3mm_D2.5mm_P10.16mm_Horizontal |  | 0.1 | LCSC [https://www.lcsc.com/product-detail/C1744271.html?s_z=n_resistor] | C1744271
mosfet | Q2 |  | P-Channel 100V 23A 140W Through Hole TO-220 | Infineon | IRF9540NPBF | IRF9540NPBF | TO-220-3_L10.0-W4.5-P2.54-L | TO-220-3_L10.0-W4.5-P2.54-L | 1.36 | LCSC [https://www.lcsc.com/product-detail/C2575.html?s_z=n_p%2520mosfet] | C2575 | switched 5V rail
TOTAL |  |  |  |  |  |  |  |  | 5.56

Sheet: MCU
Component | Label | Value | Description | Manufacturer | Manufacturer Part Number | Symbol | Footprint | 3dModel | Price (USD) | Supplier | Supplier Part Number | Notes
esp32 s3 wroom 1U module | U3 |  | 2.4GHz ESP32-S3R8 On-board PCB Antenna -98.2dBm SMD,25.5x18mm RF Transceiver Modules and Modems RoHS | ESPRESSIF | ESP32-S3-WROOM-1-N16R8 | ESP32-S3-WROOM-1(N16R8) | WIRELM-SMD_ESP32-S3-WROOM-1 | WIRELM-SMD_ESP32-S3-WROOM-1 | 5.61 | LCSC [https://www.lcsc.com/product-detail/C2913202.html?s_z=n_C2913202] | C2913202
tantalum capacitor | C6 | 22 uF | 22uF ±10% 25V Tantalum Capacitors Through Hole,P=2.54mm | KNSCHA | 178MU0035 | C_Polarized | CAP-TH_BD4.8-P2.54-D0.5-RD | CAP-TH_BD4.8-P2.54-D0.5-RD | 0.33 | LCSC [https://www.lcsc.com/product-detail/C18164676.html] | C18164676 | decoupling capacitor connected to pin2
ceramic capacitor | C7 | 100 nF (0.1 uF) | 100nF ±10% 50V Ceramic Capacitor X7R Through Hole,P=2.5mm | VISHAY | K104K10X7RF5UL2 | C | CAP-TH_L3.6-W2.3-P2.50-D0.5 | CAP-TH_L3.6-W2.3-P2.50-D0.5 | 0.2 | LCSC https://www.lcsc.com/product-detail/C1620058.html | C1620058 | decoupling capacitor connected to pin2
resistor | R5 | 10k | 10kΩ 250mW Metal Film Resistor ±100ppm/℃ ±1% Through Hole,D2.4xL6.3mm Through Hole Resistors RoHS | YAGEO | MFR-25FRF52-5K1 | R | R_Axial_DIN0207_L6.3mm_D2.5mm_P10.16mm_Horizontal |  | 0.1 | LCSC [https://www.lcsc.com/product-detail/C1744271.html?s_z=n_resistor] | C1744271
capacitor | C20 | 100nF
resistor* | R6 | 10k | 10kΩ 250mW Metal Film Resistor ±100ppm/℃ ±1% Through Hole,D2.4xL6.3mm Through Hole Resistors RoHS | YAGEO | MFR-25FRF52-5K1 | R | R_Axial_DIN0207_L6.3mm_D2.5mm_P10.16mm_Horizontal |  | 0.1 | LCSC [https://www.lcsc.com/product-detail/C1744271.html?s_z=n_resistor] | C1744271
resistor | R30 | 4.7k | 4.7kΩ 250mW Metal Film Resistor ±100ppm/℃ ±1% Through Hole,D2.4xL6.3mm Through Hole Resistors RoHS | YAGEO | MFR-25FRF52-5K1 | R | R_Axial_DIN0207_L6.3mm_D2.5mm_P10.16mm_Horizontal |  | 0.1 | LCSC [https://www.lcsc.com/product-detail/C1744271.html?s_z=n_resistor] | C1744271
resistor | R31 | 4.7k | 4.7kΩ 250mW Metal Film Resistor ±100ppm/℃ ±1% Through Hole,D2.4xL6.3mm Through Hole Resistors RoHS | YAGEO | MFR-25FRF52-5K1 | R | R_Axial_DIN0207_L6.3mm_D2.5mm_P10.16mm_Horizontal |  | 0.1 | LCSC [https://www.lcsc.com/product-detail/C1744271.html?s_z=n_resistor] | C1744271
resistor | R32 | 4.7k | 4.7kΩ 250mW Metal Film Resistor ±100ppm/℃ ±1% Through Hole,D2.4xL6.3mm Through Hole Resistors RoHS | YAGEO | MFR-25FRF52-5K1 | R | R_Axial_DIN0207_L6.3mm_D2.5mm_P10.16mm_Horizontal |  | 0.1 | LCSC [https://www.lcsc.com/product-detail/C1744271.html?s_z=n_resistor] | C1744271
resistor | R33 | 4.7k | 4.7kΩ 250mW Metal Film Resistor ±100ppm/℃ ±1% Through Hole,D2.4xL6.3mm Through Hole Resistors RoHS | YAGEO | MFR-25FRF52-5K1 | R | R_Axial_DIN0207_L6.3mm_D2.5mm_P10.16mm_Horizontal |  | 0.1 | LCSC [https://www.lcsc.com/product-detail/C1744271.html?s_z=n_resistor] | C1744271
usb connector* | U4 |  | USB-C (USB TYPE-C) Receptacle Connector 16 Position Right AnglePosition Surface Mount | XUNPU | TYPEC-306DDW-ARP16 | TYPEC-306DDW-ARP16 | USB-C-TH_TYPEC-306DDW-ARP16 | USB-C-TH_TYPEC-306DDW-ARP16 | 0.68 | LCSC [https://www.lcsc.com/product-detail/C2840393.html?s_z=n_Micro%2520USB%2520B%2520Receptacle%25205P] | C2840393
schottky Diode | D3 |  | Diode Independent 40V 5A Through Hole DO-27 | LGE | SR540 | SR540_C432150 | DO-27_BD5.2-L8.9-P12.90-D1.5-RD |  | 0.1 | LCSC [https://www.lcsc.com/product-detail/C432150.html?s_z=n_SR540] | C432150
resistor | R3 | 5.1 k | 5.1kΩ 250mW Metal Film Resistor ±100ppm/℃ ±1% Through Hole,D2.4xL6.3mm Through Hole Resistors RoHS | YAGEO | MFR-25FRF52-5K1 | R | R_Axial_DIN0207_L6.3mm_D2.5mm_P10.16mm_Horizontal |  | 0.1 | LCSC [https://www.lcsc.com/product-detail/C1744271.html?s_z=n_resistor] | C1744271 | connect A5 to this resistor then to ground
resistor | R4 | 5.1k | 5.1kΩ 250mW Metal Film Resistor ±100ppm/℃ ±1% Through Hole,D2.4xL6.3mm Through Hole Resistors RoHS | YAGEO | MFR-25FRF52-5K1 | R | R_Axial_DIN0207_L6.3mm_D2.5mm_P10.16mm_Horizontal |  | 0.1 | LCSC [https://www.lcsc.com/product-detail/C1744271.html?s_z=n_resistor] | C1744271 | connect B5 to this resistor then to ground
USB to UART chip | U5 |  | Transceiver 2Mbps USB 2.0 SOP-16 Interface Controllers RoHS | WCH | CH340C | CH340C | SOP-16_L10.0-W3.9-P1.27-LS6.0-BL | SOP-16_L9.9-W3.9-H1.5-LS6.0-P1.27 | 0.57 | LCSC [https://www.lcsc.com/product-detail/C84681.html?s_z=n_CH340C] | C84681
capacitor | C21 | 0.1uF
electrolytic capacitor | C22 | 10uF | 10uF 25V Aluminum Electrolytic Capacitors Through Hole,D4xL7mm 1000hrs@105℃ | PANASONIC | EEAGA1E100H | C_polarized | CAP-TH_BD4.0-P2.50-D0.6-FD | CAP-TH_BD4.0-P2.50-D0.6-FD | 0.1 | LCSC [https://www.lcsc.com/product-detail/C713351.html] | C713351
capacitor | C23 | 0.1uF
tactile button [EN] | S1 |  | Tactile Switch SPST 180gf 4.3mm Gull Wing 6mm x 6mm Surface Mount | Yuandi | TS-1095PS-A1B2-C3D2 | SW | KEY-SMD_4P-L6.0-W6.0-P3.90-LS9.0 | KEY-SMD_4P-L6.0-W6.0-H8.0-P3.90-LS9.0 | 0.53 | LCSC [https://www.lcsc.com/product-detail/C2834918.html?s_z=n_push%2520button] | C2834918
ceramic capacitor* | C8 | 1 uF | 1uF ±10% 50V Ceramic Capacitor X7R Through Hole,P=5.08mm | KNSCHA | 178MU0014 | C | CAP-TH_L4.4-W4.0-P5.08-D0.6 | CAP-TH_L4.4-W4.0-P5.08-D0.6 | 0.1 | LCSC [https://www.lcsc.com/product-detail/C5632438.html] | C5632438
tactile button [BOOT] | S2 |  | Tactile Switch SPST 180gf 4.3mm Gull Wing 6mm x 6mm Surface Mount | Yuandi | TS-1095PS-A1B2-C3D2 | SW | KEY-SMD_4P-L6.0-W6.0-P3.90-LS9.0 | KEY-SMD_4P-L6.0-W6.0-H8.0-P3.90-LS9.0 | 0.53 | LCSC [https://www.lcsc.com/product-detail/C2834918.html?s_z=n_push%2520button] | C2834918
ceramic capacitor* | C9 | 1 uF | 1uF ±10% 50V Ceramic Capacitor X7R Through Hole,P=5.08mm | KNSCHA | 178MU0014 | C | CAP-TH_L4.4-W4.0-P5.08-D0.6 | CAP-TH_L4.4-W4.0-P5.08-D0.6 | 0.1 | LCSC [https://www.lcsc.com/product-detail/C5632438.html] | C5632438
LED [3.3V] | LED1 |  | Red 632nm LED Indication - Discrete 2V Through Hole,D=5mm | EVERLIGHT | 333-2SURD/S530-A3 | LED | LED-TH_BD5.9-P2.54-RD_RED | LED-TH_BD5.9-P2.54-RD_RED | 0.1 | LCSC [https://www.lcsc.com/product-detail/C87271.html?s_z=n_Everlight%2520Elec%2520333-2SURD%252FS530-A3] | C87271
resistor | R7 | 1k | 1kΩ 250mW Metal Film Resistor ±100ppm/℃ ±1% Through Hole,D2.4xL6.3mm Through Hole Resistors RoHS | YAGEO | MFR-25FRF52-5K1 | R | R_Axial_DIN0207_L6.3mm_D2.5mm_P10.16mm_Horizontal |  | 0.1 | LCSC [https://www.lcsc.com/product-detail/C1744271.html?s_z=n_resistor] | C1744271
LED [5V] | LED2 |  | Red 632nm LED Indication - Discrete 2V Through Hole,D=5mm | EVERLIGHT | 333-2SURD/S530-A3 | LED | LED-TH_BD5.9-P2.54-RD_RED | LED-TH_BD5.9-P2.54-RD_RED | 0.1 | LCSC [https://www.lcsc.com/product-detail/C87271.html?s_z=n_Everlight%2520Elec%2520333-2SURD%252FS530-A3] | C87271
resistor* | R26 | 2.2k | 2.2kΩ 250mW Metal Film Resistor ±100ppm/℃ ±1% Through Hole,D2.4xL6.3mm Through Hole Resistors RoHS | YAGEO | MFR-25FRF52-5K1 | R | R_Axial_DIN0207_L6.3mm_D2.5mm_P10.16mm_Horizontal |  | 0.1 | LCSC [https://www.lcsc.com/product-detail/C1744271.html?s_z=n_resistor] | C1744271
 | LED3
LED [Switched 5V] | D13 |  | Red 632nm LED Indication - Discrete 2V Through Hole,D=5mm | EVERLIGHT | 333-2SURD/S530-A3 | LED | LED-TH_BD5.9-P2.54-RD_RED | LED-TH_BD5.9-P2.54-RD_RED | 0.1 | LCSC [https://www.lcsc.com/product-detail/C87271.html?s_z=n_Everlight%2520Elec%2520333-2SURD%252FS530-A3] | C87271
resistor* | R27 | 2.2k | 2.2kΩ 250mW Metal Film Resistor ±100ppm/℃ ±1% Through Hole,D2.4xL6.3mm Through Hole Resistors RoHS | YAGEO | MFR-25FRF52-5K1 | R | R_Axial_DIN0207_L6.3mm_D2.5mm_P10.16mm_Horizontal |  | 0.1 | LCSC [https://www.lcsc.com/product-detail/C1744271.html?s_z=n_resistor] | C1744271
LED [12V] | LED4 |  | Red 632nm LED Indication - Discrete 2V Through Hole,D=5mm | EVERLIGHT | 333-2SURD/S530-A3 | LED | LED-TH_BD5.9-P2.54-RD_RED | LED-TH_BD5.9-P2.54-RD_RED | 0.1 | LCSC [https://www.lcsc.com/product-detail/C87271.html?s_z=n_Everlight%2520Elec%2520333-2SURD%252FS530-A3] | C87271
resistor* | R28 | 10k | 10kΩ 250mW Metal Film Resistor ±100ppm/℃ ±1% Through Hole,D2.4xL6.3mm Through Hole Resistors RoHS | YAGEO | MFR-25FRF52-5K1 | R | R_Axial_DIN0207_L6.3mm_D2.5mm_P10.16mm_Horizontal |  | 0.1 | LCSC [https://www.lcsc.com/product-detail/C1744271.html?s_z=n_resistor] | C1744271
TOTAL |  |  |  |  |  |  |  |  | 9.85

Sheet: ACTUATORS
Component | Label | Value | Description | Manufacturer | Manufacturer Part Number | Symbol | Footprint | 3dModel | Price (USD) | Supplier | Supplier Part Number | Notes
relay | K1 |  | Power Relay 1 Form C: 1C (SPDT-CO) 5V Coil Through Hole,15.6x19.2mm | Songle Relay | SRD-05VDC-SL-C | SRD-05VDC-SL-C | RELAY-TH_SRD-XXVDC-XL-C | RELAY-TH_L19.2-W15.6-H15.8 | 1.51 | LCSC [https://www.lcsc.com/product-detail/C35449.html?s_z=n_songle%2520relay%2520%2520C37482] | C35449 | 5 terminal relay with coil of 5V
diode | D5 |  | Diode 1kV 1A Through Hole DO-41 | onsemi | 1N4007G | D | DO-41_BD2.4-L4.7-P8.70-D0.9-RD | DO-41_D2.4-L4.7-P8.70 | 0.05 | LCSC [https://www.lcsc.com/product-detail/C232439.html?s_z=n_1N4007] | C232439
transistor | Q3 |  | Bipolar (BJT) Transistor NPN 40V 600mA 250MHz 625mW Through Hole TO-92 | ST(Semtech) | 2N2222A | 2N2222 | TO-92-3_L4.9-W3.7-P1.27-L | TO-92-3_L4.9-W3.7-P1.27-L | 0.04 | LCSC [https://www.lcsc.com/product-detail/C118536.html?s_z=n_2N2222] | C118536 | required a npn (2N222)
resistor | R8 | 1k | 1kΩ 250mW Metal Film Resistor ±100ppm/℃ ±1% Through Hole,D2.4xL6.3mm Through Hole Resistors RoHS | YAGEO | MFR-25FRF52-5K1 | R | R_Axial_DIN0207_L6.3mm_D2.5mm_P10.16mm_Horizontal |  | 0.1 | LCSC [https://www.lcsc.com/product-detail/C1744271.html?s_z=n_resistor] | C1744271
electrolytic capacitor | C24 | 100 uF | 100uF 50V Aluminum Electrolytic Capacitors Through Hole,D6.3xL11mm 9000hrs@105℃ | Ymin | LKMC1101H101MF | C_Polarized | CAP-TH_BD6.3-P2.50-D1.0-FD | CAP-TH_BD6.3-P2.50-D1.0-FD | 0.1 | LCSC [https://www.lcsc.com/product-detail/C442995.html] | C442995
diode | D6 |  | Diode 1kV 1A Through Hole DO-41 | onsemi | 1N4007G | D | DO-41_BD2.4-L4.7-P8.70-D0.9-RD | DO-41_D2.4-L4.7-P8.70 | 0.05 | LCSC [https://www.lcsc.com/product-detail/C232439.html?s_z=n_1N4007] | C232439 | required a npn (2N222)
ceramic capacitor | C10 | 0.1 uF | 100nF ±10% 50V Ceramic Capacitor X7R Through Hole,P=2.5mm | VISHAY | K104K10X7RF5UL2 | C | Capacitor_THT:C_Disc_D5.0mm_W2.5mm_P2.50mm |  | 0.64 | LCSC https://www.lcsc.com/product-detail/C1620058.html | C1620058
valve connector | J2 |  | 2 Position Wire to Board Terminal Block Through Hole 5.08mm | Cixi Kefa Elec | KF128-5.08-2P-AA | KF128-5.08-2P | CONN-TH_P5.08_KF128-5.08-2P | CONN-TH_P5.08_KF128-5.08-2P | 0.91 | LCSC [https://www.lcsc.com/product-detail/C474952.html?s_z=n_C474952] | C474952 | Input 12V from the battery consider a two pin connector Screw Terminal Block (2-pin, 5.08mm pitch)
relay | K2 |  | Power Relay 1 Form C: 1C (SPDT-CO) 5V Coil Through Hole,15.6x19.2mm | Songle Relay | SRD-05VDC-SL-C | SRD-05VDC-SL-C | RELAY-TH_SRD-XXVDC-XL-C | RELAY-TH_L19.2-W15.6-H15.8 | 1.51 | LCSC [https://www.lcsc.com/product-detail/C35449.html?s_z=n_songle%2520relay%2520%2520C37482] | C35449 | 5 terminal relay with coil of 5V
diode | D7 |  | Diode 1kV 1A Through Hole DO-41 | onsemi | 1N4007G | D | DO-41_BD2.4-L4.7-P8.70-D0.9-RD | DO-41_D2.4-L4.7-P8.70 | 0.05 | LCSC [https://www.lcsc.com/product-detail/C232439.html?s_z=n_1N4007] | C232439
transistor | Q4 |  | Bipolar (BJT) Transistor NPN 40V 600mA 250MHz 625mW Through Hole TO-92 | ST(Semtech) | 2N2222A | 2N2222 | TO-92-3_L4.9-W3.7-P1.27-L | TO-92-3_L4.9-W3.7-P1.27-L | 0.04 | LCSC [https://www.lcsc.com/product-detail/C118536.html?s_z=n_2N2222] | C118536 | required a npn (2N222)
resistor | R9 | 1k | 1kΩ 250mW Metal Film Resistor ±100ppm/℃ ±1% Through Hole,D2.4xL6.3mm Through Hole Resistors RoHS | YAGEO | MFR-25FRF52-5K1 | R | R_Axial_DIN0207_L6.3mm_D2.5mm_P10.16mm_Horizontal |  | 0.1 | LCSC [https://www.lcsc.com/product-detail/C1744271.html?s_z=n_resistor] | C1744271
electrolytic capacitor | C11 | 100 uF | 100uF 10V Aluminum Electrolytic Capacitors Through Hole,D5xL11mm 4000hrs@105℃ | Rubycon | 10YXF100MFFC5X11 | C_Polarized | CAP-TH_BD5.0-P2.00-D0.8-FD | CAP-TH_D5.0×H7.0×P2.0 | 0.55 | LCSC [https://www.lcsc.com/product-detail/C334315.html] | C334315
diode | D8 |  | Diode 1kV 1A Through Hole DO-41 | onsemi | 1N4007G | D | DO-41_BD2.4-L4.7-P8.70-D0.9-RD | DO-41_D2.4-L4.7-P8.70 | 0.05 | LCSC [https://www.lcsc.com/product-detail/C232439.html?s_z=n_1N4007] | C232439 | required a npn (2N222)
ceramic capacitor | C12 | 0.1 uF | 100nF ±10% 50V Ceramic Capacitor X7R Through Hole,P=2.5mm | VISHAY | K104K10X7RF5UL2 | C | Capacitor_THT:C_Disc_D5.0mm_W2.5mm_P2.50mm |  | 0.64 | LCSC https://www.lcsc.com/product-detail/C1620058.html | C1620058
pump connector | J3 |  | 2 Position Wire to Board Terminal Block Through Hole 5.08mm | Cixi Kefa Elec | KF128-5.08-2P-AA | KF128-5.08-2P | CONN-TH_P5.08_KF128-5.08-2P | CONN-TH_P5.08_KF128-5.08-2P | 0.91 | LCSC [https://www.lcsc.com/product-detail/C474952.html?s_z=n_C474952] | C474952 | Input 12V from the battery consider a two pin connector Screw Terminal Block (2-pin, 5.08mm pitch)
relay | K3 |  | Power Relay 1 Form C: 1C (SPDT-CO) 5V Coil Through Hole,15.6x19.2mm | Songle Relay | SRD-05VDC-SL-C | SRD-05VDC-SL-C | RELAY-TH_SRD-XXVDC-XL-C | RELAY-TH_L19.2-W15.6-H15.8 | 1.51 | LCSC [https://www.lcsc.com/product-detail/C35449.html?s_z=n_songle%2520relay%2520%2520C37482] | C35449 | 5 terminal relay with coil of 5V
diode | D9 |  | Diode 1kV 1A Through Hole DO-41 | onsemi | 1N4007G | D | DO-41_BD2.4-L4.7-P8.70-D0.9-RD | DO-41_D2.4-L4.7-P8.70 | 0.05 | LCSC [https://www.lcsc.com/product-detail/C232439.html?s_z=n_1N4007] | C232439
transistor | Q5 |  | Bipolar (BJT) Transistor NPN 40V 600mA 250MHz 625mW Through Hole TO-92 | ST(Semtech) | 2N2222A | 2N2222 | TO-92-3_L4.9-W3.7-P1.27-L | TO-92-3_L4.9-W3.7-P1.27-L | 0.04 | LCSC [https://www.lcsc.com/product-detail/C118536.html?s_z=n_2N2222] | C118536 | required a npn (2N222)
resistor | R10 | 1k | 1kΩ 250mW Metal Film Resistor ±100ppm/℃ ±1% Through Hole,D2.4xL6.3mm Through Hole Resistors RoHS | YAGEO | MFR-25FRF52-5K1 | R | R_Axial_DIN0207_L6.3mm_D2.5mm_P10.16mm_Horizontal |  | 0.1 | LCSC [https://www.lcsc.com/product-detail/C1744271.html?s_z=n_resistor] | C1744271
electrolytic capacitor | C13 | 100 uF | 100uF 10V Aluminum Electrolytic Capacitors Through Hole,D5xL11mm 4000hrs@105℃ | Rubycon | 10YXF100MFFC5X11 | C_Polarized | CAP-TH_BD5.0-P2.00-D0.8-FD | CAP-TH_D5.0×H7.0×P2.0 | 0.55 | LCSC [https://www.lcsc.com/product-detail/C334315.html] | C334315
diode | D10 |  | Diode 1kV 1A Through Hole DO-41 | onsemi | 1N4007G | D | DO-41_BD2.4-L4.7-P8.70-D0.9-RD | DO-41_D2.4-L4.7-P8.70 | 0.05 | LCSC [https://www.lcsc.com/product-detail/C232439.html?s_z=n_1N4007] | C232439 | required a npn (2N222)
ceramic capacitor | C14 | 0.1 uF | 100nF ±10% 50V Ceramic Capacitor X7R Through Hole,P=2.5mm | VISHAY | K104K10X7RF5UL2 | C | Capacitor_THT:C_Disc_D5.0mm_W2.5mm_P2.50mm |  | 0.64 | LCSC https://www.lcsc.com/product-detail/C1620058.html | C1620058
UV lamp connector | J4 |  | 2 Position Wire to Board Terminal Block Through Hole 5.08mm | Cixi Kefa Elec | KF128-5.08-2P-AA | KF128-5.08-2P | CONN-TH_P5.08_KF128-5.08-2P | CONN-TH_P5.08_KF128-5.08-2P | 0.91 | LCSC [https://www.lcsc.com/product-detail/C474952.html?s_z=n_C474952] | C474952 | Input 12V from the battery consider a two pin connector Screw Terminal Block (2-pin, 5.08mm pitch)
TOTAL |  |  |  |  |  |  |  |  | 11.1

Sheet: SENSORS
Component | Label | Value | Description | Manufacturer | Manufacturer Part Number | Symbol | Footprint | 3dModel | Price (USD) | Supplier | Supplier Part Number | Notes
connector (Turbidity) | J5 |  | 3 Position Wire to Board Terminal Block Through Hole 3.5mm | Cixi Kefa Elec | KF350-3.5-3P | KF350-3.5-3P | CONN-TH_3P-P3.50_KF350-3.5-3P | CONN-TH_3P-P3.50_KF350-3.5-3P | 0.2 | LCSC [https://www.lcsc.com/product-detail/C474893.html?s_z=n_KF350-3P] | C474893 | Strip the wires and screw them into the connector
resistor | R11 | 3.3k | 3.3kΩ 250mW Metal Film Resistor ±100ppm/℃ ±1% Through Hole,D2.4xL6.3mm Through Hole Resistors RoHS | YAGEO | MFR-25FRF52-5K1 | R | R_Axial_DIN0207_L6.3mm_D2.5mm_P10.16mm_Horizontal |  | 0.1 | LCSC [https://www.lcsc.com/product-detail/C1744271.html?s_z=n_resistor] | C1744271
resistor | R12 | 4.7k | 4.7kΩ 250mW Metal Film Resistor ±100ppm/℃ ±1% Through Hole,D2.4xL6.3mm Through Hole Resistors RoHS | YAGEO | MFR-25FRF52-5K1 | R | R_Axial_DIN0207_L6.3mm_D2.5mm_P10.16mm_Horizontal |  | 0.1 | LCSC [https://www.lcsc.com/product-detail/C1744271.html?s_z=n_resistor] | C1744271
ceremaic capacitor | C15 | 100 nF | 100 nF (0.1 uF) | 100nF ±10% 50V Ceramic Capacitor X7R Through Hole,P=2.5mm | VISHAY | K104K10X7RF5UL2 | C | Capacitor_THT:C_Disc_D5.0mm_W2.5mm_P2.50mm |  | 0.64 | LCSC https://www.lcsc.com/product-detail/C1620058.html | C1620058 | decoupling capacitor connected to pin2
connector (Pressure) | J6 |  | 3 Position Wire to Board Terminal Block Through Hole 3.5mm | Cixi Kefa Elec | KF350-3.5-3P | KF350-3.5-3P | CONN-TH_3P-P3.50_KF350-3.5-3P | CONN-TH_3P-P3.50_KF350-3.5-3P | 0.2 | LCSC [https://www.lcsc.com/product-detail/C474893.html?s_z=n_KF350-3P] | C474893 | Strip the wires and screw them into the connector
resistor | R13 | 3.3k | 3.3kΩ 250mW Metal Film Resistor ±100ppm/℃ ±1% Through Hole,D2.4xL6.3mm Through Hole Resistors RoHS | YAGEO | MFR-25FRF52-5K1 | R | R_Axial_DIN0207_L6.3mm_D2.5mm_P10.16mm_Horizontal |  | 0.1 | LCSC [https://www.lcsc.com/product-detail/C1744271.html?s_z=n_resistor] | C1744271
resistor | R14 | 4.7k | 4.7kΩ 250mW Metal Film Resistor ±100ppm/℃ ±1% Through Hole,D2.4xL6.3mm Through Hole Resistors RoHS | YAGEO | MFR-25FRF52-5K1 | R | R_Axial_DIN0207_L6.3mm_D2.5mm_P10.16mm_Horizontal |  | 0.1 | LCSC [https://www.lcsc.com/product-detail/C1744271.html?s_z=n_resistor] | C1744271
ceremaic capacitor | C16 | 100 nF | 100 nF (0.1 uF) | 100nF ±10% 50V Ceramic Capacitor X7R Through Hole,P=2.5mm | VISHAY | K104K10X7RF5UL2 | C | Capacitor_THT:C_Disc_D5.0mm_W2.5mm_P2.50mm |  | 0.64 | LCSC https://www.lcsc.com/product-detail/C1620058.html | C1620058 | decoupling capacitor connected to pin2
connector (water flow) | J7 |  | 3 Position Wire to Board Terminal Block Through Hole 3.5mm | Cixi Kefa Elec | KF350-3.5-3P | KF350-3.5-3P | CONN-TH_3P-P3.50_KF350-3.5-3P | CONN-TH_3P-P3.50_KF350-3.5-3P | 0.2 | LCSC [https://www.lcsc.com/product-detail/C474893.html?s_z=n_KF350-3P] | C474893 | Strip the wires and screw them into the connector
resistor | R15 | 3.3k | 3.3kΩ 250mW Metal Film Resistor ±100ppm/℃ ±1% Through Hole,D2.4xL6.3mm Through Hole Resistors RoHS | YAGEO | MFR-25FRF52-5K1 | R | R_Axial_DIN0207_L6.3mm_D2.5mm_P10.16mm_Horizontal |  | 0.1 | LCSC [https://www.lcsc.com/product-detail/C1744271.html?s_z=n_resistor] | C1744271
resistor | R16 | 4.7k | 4.7kΩ 250mW Metal Film Resistor ±100ppm/℃ ±1% Through Hole,D2.4xL6.3mm Through Hole Resistors RoHS | YAGEO | MFR-25FRF52-5K1 | R | R_Axial_DIN0207_L6.3mm_D2.5mm_P10.16mm_Horizontal |  | 0.1 | LCSC [https://www.lcsc.com/product-detail/C1744271.html?s_z=n_resistor] | C1744271
connector (color sensor) | J8 |  | 3 Position Wire to Board Terminal Block Through Hole 3.5mm | Cixi Kefa Elec | KF350-3.5-3P | KF350-3.5-3P and KF350-3.5-2P | CONN-TH_3P-P3.50_KF350-3.5-3P and CONN TH_P3.50_KF350-3.5-2P | CONN-TH_3P-P3.50_KF350-3.5-3P and CONN-TH_P3.50_KF350-3.5-2P | 0.4 | LCSC [https://www.lcsc.com/product-detail/C474893.html?s_z=n_KF350-3P] | C474893 and C474892 | 5P required which is not available on LCSC. Solution, use a 3P and 2P connected to form 5P
connector (water level) | J9 |  | 2 Position Wire to Board Terminal Block Through Hole 3.5mm | Cixi Kefa Elec | KF350-3.5-2P | KF350-3.5-2P | CONN-TH_P3.50_KF350-3.5-2P | CONN-TH_P3.50_KF350-3.5-2P | 0.2 | LCSC [https://www.lcsc.com/product-detail/C474892.html?s_z=n_KF350-3.5-4P] | C474892 | Add 2P connectors
resistor | R17 | 3.3k | 3.3kΩ 250mW Metal Film Resistor ±100ppm/℃ ±1% Through Hole,D2.4xL6.3mm Through Hole Resistors RoHS | YAGEO | MFR-25FRF52-5K1 | R | R_Axial_DIN0207_L6.3mm_D2.5mm_P10.16mm_Horizontal |  | 0.1 | LCSC [https://www.lcsc.com/product-detail/C1744271.html?s_z=n_resistor] | C1744271
resistor | R18 | 4.7k | 4.7kΩ 250mW Metal Film Resistor ±100ppm/℃ ±1% Through Hole,D2.4xL6.3mm Through Hole Resistors RoHS | YAGEO | MFR-25FRF52-5K1 | R | R_Axial_DIN0207_L6.3mm_D2.5mm_P10.16mm_Horizontal |  | 0.1 | LCSC [https://www.lcsc.com/product-detail/C1744271.html?s_z=n_resistor] | C1744271
connector (TDS) | J10 |  | 3 Position Wire to Board Terminal Block Through Hole 3.5mm | Cixi Kefa Elec | KF350-3.5-3P | KF350-3.5-3P | CONN-TH_3P-P3.50_KF350-3.5-3P | CONN-TH_3P-P3.50_KF350-3.5-3P | 0.2 | LCSC [https://www.lcsc.com/product-detail/C474893.html?s_z=n_KF350-3P] | C474893 | Strip the wires and screw them into the connector
resistor | R19 | 3.3k | 3.3kΩ 250mW Metal Film Resistor ±100ppm/℃ ±1% Through Hole,D2.4xL6.3mm Through Hole Resistors RoHS | YAGEO | MFR-25FRF52-5K1 | R | R_Axial_DIN0207_L6.3mm_D2.5mm_P10.16mm_Horizontal |  | 0.1 | LCSC [https://www.lcsc.com/product-detail/C1744271.html?s_z=n_resistor] | C1744271
ceremaic capacitor | C17 | 100 nF | 100 nF (0.1 uF) | 100nF ±10% 50V Ceramic Capacitor X7R Through Hole,P=2.5mm | VISHAY | K104K10X7RF5UL2 | C | Capacitor_THT:C_Disc_D5.0mm_W2.5mm_P2.50mm |  | 0.64 | LCSC https://www.lcsc.com/product-detail/C1620058.html | C1620058 | decoupling capacitor connected to pin2
connector (PH) | J11 |  | 3 Position Wire to Board Terminal Block Through Hole 3.5mm | Cixi Kefa Elec | KF350-3.5-3P | KF350-3.5-3P | CONN-TH_3P-P3.50_KF350-3.5-3P | CONN-TH_3P-P3.50_KF350-3.5-3P | 0.2 | LCSC [https://www.lcsc.com/product-detail/C474893.html?s_z=n_KF350-3P] | C474893 | Strip the wires and screw them into the connector
resistor | R20 | 3.3k | 3.3kΩ 250mW Metal Film Resistor ±100ppm/℃ ±1% Through Hole,D2.4xL6.3mm Through Hole Resistors RoHS | YAGEO | MFR-25FRF52-5K1 | R | R_Axial_DIN0207_L6.3mm_D2.5mm_P10.16mm_Horizontal |  | 0.1 | LCSC [https://www.lcsc.com/product-detail/C1744271.html?s_z=n_resistor] | C1744271
ceremaic capacitor | C18 | 100 nF | 100 nF (0.1 uF) | 100nF ±10% 50V Ceramic Capacitor X7R Through Hole,P=2.5mm | VISHAY | K104K10X7RF5UL2 | C | Capacitor_THT:C_Disc_D5.0mm_W2.5mm_P2.50mm |  | 0.64 | LCSC https://www.lcsc.com/product-detail/C1620058.html | C1620058 | decoupling capacitor connected to pin2
connector (voltage sensor) | J12 |  | Pin Header 6 Position 2.54mm Pitch Single Row Through Hole | CONNFLY Elec | DS1021-1x6SF11-B | DS1021-1X6SF11-B | CONN-TH_DS1021-1X6SF11-B | CONN-TH_DS1021-1X6SF11-B | 0.03 | LCSC [https://www.lcsc.com/product-detail/C7430362.html | C7430362 | using 3 2P connectors to connect via the 6pin holes down
current sense resistor | R21 | 0.01 ohms | 10mΩ 5W Through-hole Current Sense Resistor ±40ppm/℃ ±1% Through Hole Through Hole Resistors RoHS | Milliohm | HoLR-5W-10mR-1%-JZ-10 | HOLR-5W-10MR-1%-JZ-10 | RES-TH_L13.0-W4.0-P10.0 | RES-TH_L13.0-W4.0-P10.0 | 0.3 | LCSC [https://www.lcsc.com/product-detail/C508576.html?s_z=n_resistor] | C508576 | shunt resistor to increase the range of the voltage sensor connected across the vin+ and vin- terminals
TOTAL |  |  |  |  |  |  |  |  | 2.93
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

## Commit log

2026-01-09 Added new files in docs and hardware
    [BOM.xlsx]
2026-01-11 updated the bom and datasheets
    [BOM.xlsx]
2026-01-18 updated datasheets
    [BOM.xlsx]
2026-01-18 uploaded power supply simulations
2026-01-19 updated the relay circuit simulation
    [BOM.xlsx]
2026-01-22 finalized the BOM and simulations
    [BOM.xlsx, External hardware components.xlsx, PCB components.xlsx]
2026-01-22 modified pcb components bom
    [PCB components.xlsx]
2026-01-29 Impemented a miniturized version mainly focussing on pre-filtration
    [External hardware components.xlsx]
2026-01-29 updated readme file and initiated pcb designs
2026-01-31 designed the power management schematic
    [Power_Management.kicad_sch, WPS_Scaled.kicad_pcb, WPS_Scaled.kicad_sch]
2026-01-31 finalized the power management schematic
    [PCB components.xlsx]
2026-02-01 finalized with the sensors and actuator schematics
    [Actuators.kicad_sch, ESP32_Module.kicad_sch, PCB components.xlsx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]
2026-02-09 finalized the pcb schematics
    [Actuators.kicad_sch, ESP32_Module.kicad_sch, External hardware components.xlsx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]
2026-02-16 finallized pcb layout
    [Actuators.kicad_sch, ESP32_Module.kicad_sch, PCB components.xlsx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]
